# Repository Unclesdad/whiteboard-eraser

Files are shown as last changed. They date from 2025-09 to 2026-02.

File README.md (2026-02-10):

# Whiteboard Eraser

An autonomous whiteboard eraser robot built on a Raspberry Pi 5. Uses computer vision to detect markings on a whiteboard and navigates to erase them. Initially conceived as a handy and cool tool for our math teacher Mr. Perna, Mark is ready to vroom across surfaces and unmark any unwanted marks.

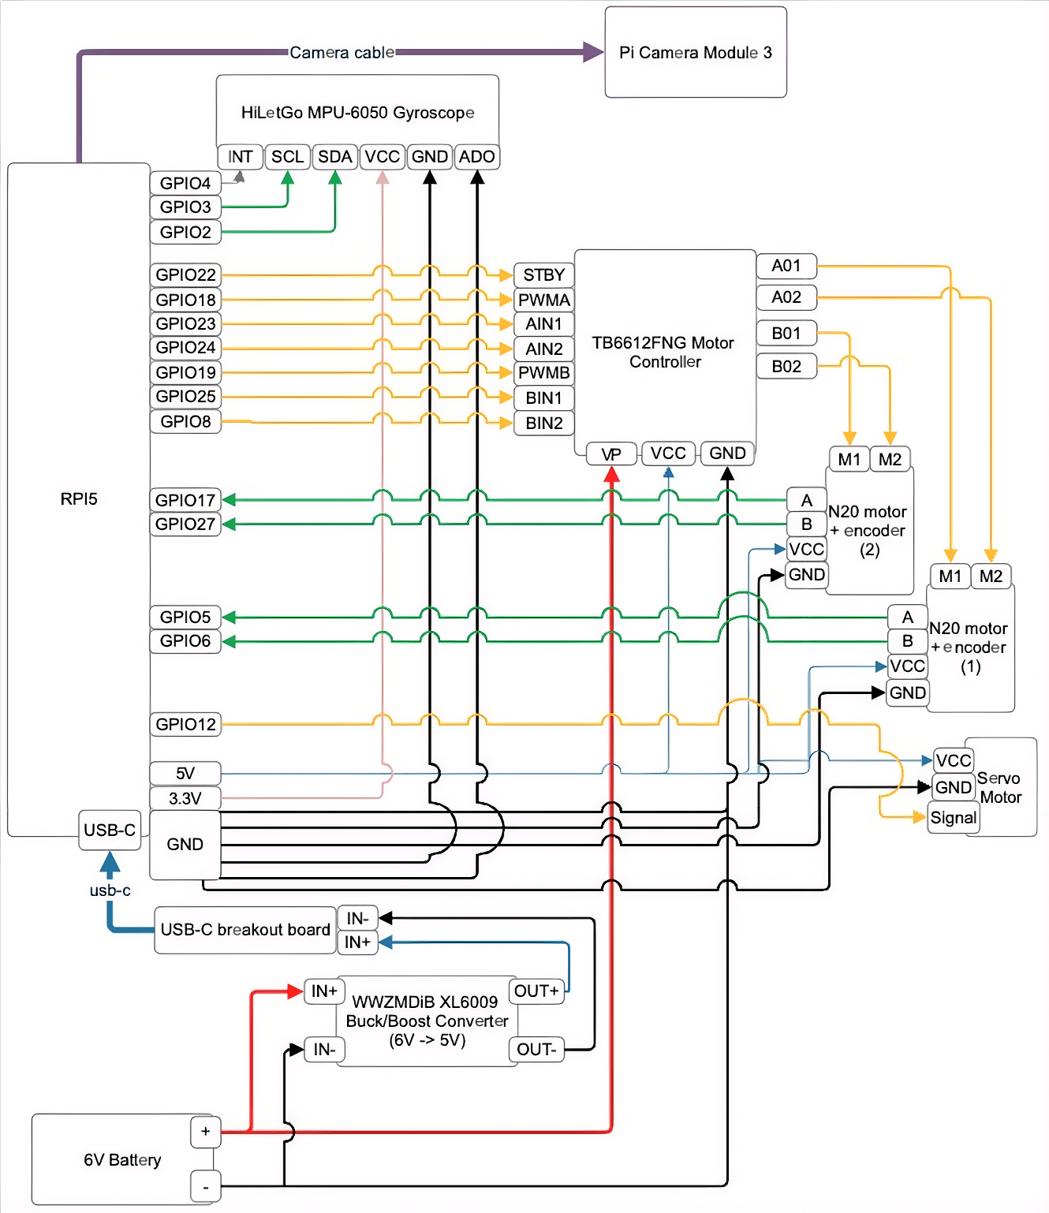
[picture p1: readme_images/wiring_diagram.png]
Wiring Diagram


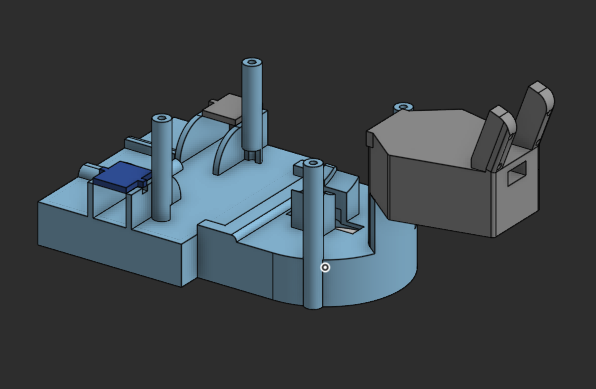
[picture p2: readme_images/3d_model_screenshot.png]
3d Model Screenshot


## Project Structure

```
whiteboard-eraser/
├── lib/                    # Hardware abstraction layer
│   ├── motor.py            # N20 motor control with encoders
│   ├── servo.py            # Steering servo control
│   └── gyro.py             # MPU-6050 gyroscope/IMU
├── src/                    # Algorithm and application code
│   ├── whiteboard_eraser_main.py   # Main control loop
│   ├── car_controller.py           # PID control for motion
│   ├── simple_marking_detector.py  # Computer vision detection
│   ├── localization.py             # Position tracking (odometry + gyro)
│   ├── mapping.py                  # Global marking map
│   ├── pathfinder.py               # A* pathfinding
│   └── ...
├── setup/                  # Installation scripts
│   ├── setup_service.sh    # Systemd service installer
│   └── install_dependencies.sh
└── ...
```

### lib/ - Hardware Abstraction

Low-level drivers that interface directly with hardware components. These modules abstract away GPIO pins, I2C communication, and PWM signals into clean Python APIs.

### src/ - Algorithms

High-level application code including computer vision, path planning, localization, and the main state machine. These modules use the hardware abstractions from `lib/` to control the robot.

## Bill of Materials

| Category | Component | Qty | Specifications | Price | Notes |
|---|---|-----|---|---|---|
| Motors | [N20 DC Gear Motor with Hall Encoder](https://a.co/d/9TnXhcp) | 4 | 6V, All-metal Gearbox, 60RPM | $22 ea | Small but powerful. Main driving force of the bot |
| Motors | [N20 DC Gear Motor w/o Encoder](https://a.co/d/ak1BJBg) | 4 | 6V, All-metal Gearbox, 60RPM | $18 ea | No encoder needed for the front wheels |
| Motor Driver | [TB6612FNG Motor Driver Board](https://www.sparkfun.com/sparkfun-motor-driver-dual-tb6612fng-1a.html) | 1 | Dual H-Bridge 1.2A per channel | $15 | |
| Steering | [Miuzei MG90S Micro Servo](https://a.co/d/aozp7PX) | 1 | 9g Metal Geared Servo Motor | $14 | 4-pack available, only need 1 for steering mechanism |
| IMU | [MPU-6050](https://a.co/d/8KAH4Vv) | 1 | 6-axis Gyroscope + Accelerometer I2C | $7 | GY-521 breakout board |
| Power | [Blomiky 6V NiMH Battery](https://a.co/d/0zdu3bS) | 1 | 2400mAh AA NiMH with SM-2P plug | $15 | RC car rechargeable battery |
| Power | [XL6009 Buck/Boost Converter](https://a.co/d/98DkTq4) | 1 | DC-DC 3.8-32V to 1.25-35V | $10 | 3-pack, adjust output to 5V for Pi5 |
| Connectivity | [Jumper Wires](https://a.co/d/bcNZuKm) | 1 set | M-F, M-M, F-F | $10 | Dupont connector wires |
| Mechanical | [Tires](https://www.injora.com/products/4pcs-1-9-108-40mm-rubber-tyre-wheel-tires-for-1-10-rc-rock-crawler) | 4 | INJORA 1.9" 108x40mm Rubber | $20 | High performance rock crawler tires |
| Magnets | [30x3mm Neodymium Magnets](https://a.co/d/8jqn8wP) | 1 set | 10 pieces | $13 | For attaching front wheels to magnetic whiteboard |
| Magnets | [2in Fishing Magnet](https://a.co/d/bWNcJSW) | 1 | Strong with hook | $10 | Main attraction force to keep car on board |

## Getting Started

See [USAGE.md](USAGE.md) for installation and usage instructions.

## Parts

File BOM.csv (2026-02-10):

Category | Component | Quantity | Specifications | Estimated Price | Purchase Link | Notes
Motors | N20 DC Gear Motor with Hall Encoder | 4 | 6V, All-metal Gearbox, L-shaped 6PIN Connector, Magnetic Hall Encoder, 60RPM | $22 each | https://a.co/d/9TnXhcp | Small but powerful. Main driving force of the bot
Motors | N20 DC Gear Motor w/o Encoder | 4 | 6V, All-metal Gearbox, Only two pins, 60RPM | $18 each | https://a.co/d/ak1BJBg | Also small but powerful. No encoder needed for the front wheels.
Motor Driver | TB6612FNG Motor Driver Board | 1 | Dual H-Bridge 1.2A per channel | $15 | https://www.sparkfun.com/sparkfun-motor-driver-dual-tb6612fng-1a.html
Steering | Miuzei MG90S Micro Servo | 1 | 9g Metal Geared Servo Motor. 4 pack | $14 | https://a.co/d/aozp7PX | 4-pack available, only need 1 for steering mechanism
IMU | MPU-6050 | 1 | 6-axis Gyroscope + Accelerometer I2C | $7 | https://a.co/d/8KAH4Vv | GY-521 breakout board
Power | Blomiky 6V NiMH Battery | 1 | 2400mAh AA NiMH with SM-2P plug + USB charge cable | $15 | https://a.co/d/0zdu3bS | RC car rechargeable battery for stunt vehicles
Power | WWZMDiB XL6009 Buck/Boost Converter | 1 | DC-DC 3.8-32V to 1.25-35V Adjustable | $10 | https://a.co/d/98DkTq4 | 3-pack, adjust output to 5V for logic boards (like pi5)
Connectivity | Jumper Wires | 1 set | Male-to-Female, Male-to-Male and Female-to-Female | $10 | https://a.co/d/bcNZuKm | Dupont connector wires
Mechanical | Tires | 4 | INJORA 1.9in 108*40mm Rubber Tires | $20 | https://www.injora.com/products/4pcs-1-9-108-40mm-rubber-tyre-wheel-tires-for-1-10-rc-rock-crawler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 | High performance rock crawler tires for 3D printed wheels
Magnets | 30x3mm Neodynium Magnets | 1 set | 10 pieces | $13 | https://a.co/d/8jqn8wP | Smaller magnets for attaching front wheels to the magnetic whiteboard
Magnets | 2in Fishing Magnet | 1 | Must have a hook and be extremely strong | $10 | https://a.co/d/bWNcJSW | Main force of attraction for the body, super strong magnet to keep car on board

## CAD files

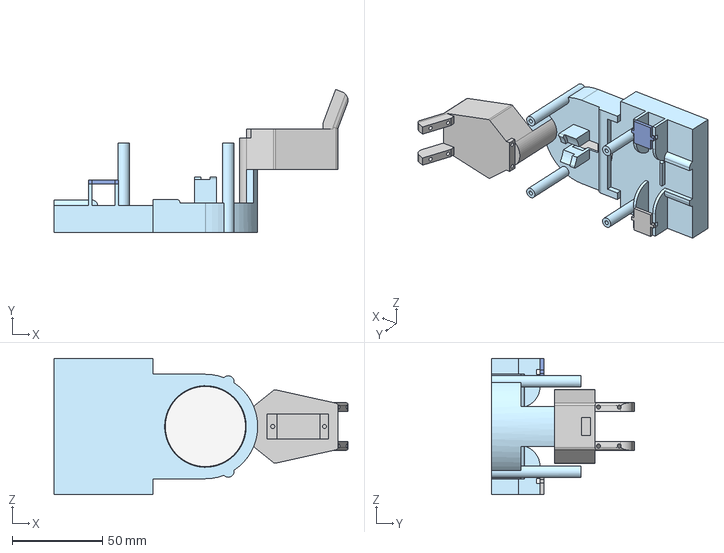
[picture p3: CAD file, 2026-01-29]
eraser car.step
163.0 x 79.3 x 75.6 mm

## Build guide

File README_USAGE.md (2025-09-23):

# Whiteboard Eraser Car - Usage Guide

## Quick Start

1. **Install dependencies:**
   ```bash
   pip install -r requirements.txt
   ```

2. **Test the system:**
   ```bash
   python test_system.py --all
   ```

3. **Run the whiteboard eraser:**
   ```bash
   python whiteboard_eraser_main.py
   ```

## Auto-Start Setup (Plug and Play)

To set up the car to start automatically when powered on:

1. **Install as a service:**
   ```bash
   sudo ./setup_service.sh
   ```

2. **Reboot the system:**
   ```bash
   sudo reboot
   ```

3. **The car will now automatically:**
   - Wait 5 seconds after boot
   - Calibrate its encoders by moving forward then backward
   - Perform a circular scan to detect markings
   - Begin systematic erasing of detected markings

4. **Monitor the service:**
   ```bash
   sudo journalctl -u whiteboard-eraser -f
   ```

## Testing Individual Components

### Test Marking Detection
```bash
python test_system.py --detection
```
Place some whiteboard images (with markings) in the directory first.

### Test Hardware Integration
```bash
python test_system.py --controller --camera
```

### Test Full System (Safe Mode)
```bash
python test_system.py --integration
```

## Command Line Options

### Main System
```bash
python whiteboard_eraser_main.py [options]

Options:
  --debug                 Enable debug mode with camera view
  --camera-width WIDTH    Camera resolution width (default: 640)
  --camera-height HEIGHT  Camera resolution height (default: 480)
  --max-speed SPEED       Maximum speed in mm/s (default: 150)
  --scan-time TIME        Maximum scan time in seconds (default: 60)
```

### Testing
```bash
python test_system.py [options]

Options:
  --all                   Run all tests
  --detection             Test marking detection only
  --localization          Test position tracking only
  --mapping               Test global mapping only
  --pathfinding           Test path planning only
  --controller            Test car control only
  --camera                Test camera integration only
  --integration           Test full system integration
```

## System Architecture

### Core Modules

1. **marking_detector.py** - Computer vision for detecting markings
2. **localization.py** - Position tracking using encoders + gyro
3. **mapping.py** - Global map of detected markings
4. **pathfinder.py** - A* pathfinding with car constraints
5. **car_controller.py** - PID control for smooth motion
6. **whiteboard_eraser_main.py** - Main control loop

### Hardware APIs (Existing)

- **motor.py** - N20 motor control with encoders
- **gyro.py** - MPU-6050 gyroscope integration
- **servo.py** - Steering servo control

## Operation States

### Startup Sequence
1. **STARTUP_DELAY** - Wait 5 seconds after power-on
2. **CALIBRATING_ENCODERS** - Move forward/backward to calibrate encoder differences
3. **INITIAL_SCAN** - Drive in circle to detect markings

### Main Operation
4. **SCANNING** - Continue detecting and mapping markings
5. **PLANNING** - Plan path to next marking cluster
6. **NAVIGATING** - Follow planned path to target
7. **ERASING** - Mark area as erased when car drives over it
8. **COMPLETED** - All markings processed

## Key Features

### Computer Vision
- Handles upside-down camera mounting (180° rotation)
- Efficient marking detection optimized for RPi5
- Real-world coordinate conversion from pixels
- Adaptive thresholding for different lighting

### Localization
- Combines wheel encoder odometry with gyroscope
- Drift-free heading using sensor fusion
- Coordinate transformations between reference frames
- Position validation and error detection

### Mapping
- Global marking map with confidence tracking
- Duplicate detection and merging
- Clustering for efficient pathfinding
- Progress tracking and persistence

### Pathfinding
- A* search with Ackermann steering constraints
- Respects minimum turning radius
- Obstacle avoidance
- Path smoothing for natural motion

### Control
- PID control for position and heading
- Smooth velocity commands
- Emergency stop capabilities
- Real-time status monitoring

## Calibration Tips

### Camera Calibration
1. Test detection on sample images first
2. Adjust `marking_threshold` if markings not detected
3. Verify coordinate conversion using known distances

### Motor Calibration
1. Check encoder tick counts per revolution
2. Measure actual wheel radius
3. Calibrate `mm_per_tick` conversion factor

### Steering Calibration
1. Verify servo center position (90°)
2. Measure actual max steering angles
3. Test turning radius calculations

## Troubleshooting

### No Markings Detected
- Check camera focus and exposure
- Verify marking contrast against whiteboard
- Test with debug mode: `--debug`

### Poor Navigation Accuracy
- Calibrate wheel encoder counts
- Check gyroscope calibration
- Verify motor speed consistency

### Path Planning Failures
- Check obstacle map boundaries
- Reduce max speed for tighter turns
- Increase planning time limit

### Hardware Issues
- Run component tests: `python test_system.py --all`
- Check GPIO connections and permissions
- Verify I2C communication for gyroscope

## Performance Optimization

### For Better Detection Speed
- Reduce camera resolution
- Lower detection frequency
- Use smaller blur kernel size

### For Better Navigation
- Increase control loop frequency
- Tune PID parameters
- Use path smoothing

### For Better Coverage
- Increase scan time
- Lower minimum confidence threshold
- Use smaller merge distance

## Safety Notes

- Always test in simulation mode first
- Use emergency stop (Ctrl+C) if needed
- Start with slow speeds for testing
- Ensure adequate clearance around whiteboard
- Monitor system status during operation

## File Output

The system saves several files during operation:

- `whiteboard_map_[timestamp].json` - Periodic map saves
- `final_whiteboard_map.json` - Complete final map
- `shutdown_map.json` - Map saved on emergency shutdown

These can be loaded later for analysis or resuming operation.

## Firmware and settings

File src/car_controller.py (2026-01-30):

#!/usr/bin/env python3
"""
Car Controller for Whiteboard Eraser Car
Implements PID control for smooth position and heading control
Integrates with existing motor.py, gyro.py, and servo.py hardware APIs
"""

import time
import threading
import sys
import os
import numpy as np
from typing import Optional, Tuple, List
from dataclasses import dataclass
from enum import Enum

# Add parent directory to path for lib imports
sys.path.insert(0, os.path.dirname(os.path.dirname(os.path.abspath(__file__))))

# Import hardware APIs
try:
    from lib.motor import N20Motor, DualMotorController
    from lib.gyro import RCCarGyro
    from lib.servo import ServoController
    import RPi.GPIO as GPIO
except ImportError:
    print("Warning: Hardware modules not available. Running in simulation mode.")

    # Mock classes for testing
    class N20Motor:
        def __init__(self, *args, **kwargs):
            self.current_speed = 0.0
            self.encoder_count = 0
        def set(self, speed): self.current_speed = speed
        def get_encoder_count(self): return self.encoder_count
        def get_revolutions(self): return self.encoder_count / 28.0
        def reset_encoder(self): self.encoder_count = 0
        def stop(self): self.current_speed = 0.0
        def cleanup(self): pass

    class DualMotorController:
        def __init__(self, *args, **kwargs): pass
        def enable(self): pass
        def disable(self): pass
        def cleanup(self): pass

    class RCCarGyro:
        def __init__(self, *args, **kwargs):
            self.angle_z = 0.0
        def calibrate(self): pass
        def start_continuous_update(self): pass
        def stop_continuous_update(self): pass
        def get_orientation(self): return (0, 0, self.angle_z)
        def reset_orientation(self): self.angle_z = 0.0

    class ServoController:
        def __init__(self, *args, **kwargs):
            self.current_angle = 90
        def set_angle(self, angle): self.current_angle = angle
        def cleanup(self): pass

    class GPIO:
        BCM = 1
        @staticmethod
        def setmode(mode): pass
        @staticmethod
        def setwarnings(flag): pass
        @staticmethod
        def cleanup(): pass

@dataclass
class PIDController:
    """PID controller for smooth control"""
    kp: float
    ki: float
    kd: float
    max_output: float = 1.0
    min_output: float = -1.0
    max_integral: float = 1.0

    def __post_init__(self):
        self.reset()

    def reset(self):
        """Reset PID controller state"""
        self.previous_error = 0.0
        self.integral = 0.0
        self.last_time = time.time()

    def update(self, error: float, dt: Optional[float] = None) -> float:
        """
        Update PID controller with new error

        Args:
            error: Current error value
            dt: Time delta (auto-calculated if None)

        Returns:
            Control output
        """
        current_time = time.time()
        if dt is None:
            dt = current_time - self.last_time

        if dt <= 0:
            return 0.0

        # Proportional term
        proportional = self.kp * error

        # Integral term with windup protection
        self.integral += error * dt
        self.integral = np.clip(self.integral, -self.max_integral, self.max_integral)
        integral = self.ki * self.integral

        # Derivative term
        derivative = self.kd * (error - self.previous_error) / dt

        # Calculate output
        output = proportional + integral + derivative
        output = np.clip(output, self.min_output, self.max_output)

        # Update state
        self.previous_error = error
        self.last_time = current_time

        return output

class CarState(Enum):
    """Car operational states"""
    STOPPED = "stopped"
    MANUAL_CONTROL = "manual"
    POSITION_CONTROL = "position"
    PATH_FOLLOWING = "path_following"
    EMERGENCY_STOP = "emergency"

@dataclass
class CarStatus:
    """Current car status"""
    state: CarState
    position_x: float
    position_y: float
    heading: float
    linear_velocity: float
    angular_velocity: float
    left_motor_speed: float
    right_motor_speed: float
    steering_angle: float
    timestamp: float

class CarController:
    """
    High-level car controller with PID control for smooth motion
    """

    def __init__(self,
                 # Motor configuration
                 left_motor_pins: dict = None,
                 right_motor_pins: dict = None,
                 standby_pin: int = 22,

                 # Servo configuration
                 servo_pin: int = 12,

                 # Gyro configuration
                 gyro_sda_pin: int = 2,
                 gyro_scl_pin: int = 3,

                 # Car physical parameters
                 wheelbase_mm: float = 110.0,
                 track_width_mm: float = 110.0,
                 wheel_radius_mm: float = 30.0,
                 max_speed_mm_s: float = 200.0,

                 # Control parameters
                 update_rate_hz: float = 50.0):
        """
        Initialize car controller

        Args:
            left_motor_pins: Dict with keys: pwm_pin, dir1_pin, dir2_pin, enc_a_pin, enc_b_pin
            right_motor_pins: Dict with keys: pwm_pin, dir1_pin, dir2_pin, enc_a_pin, enc_b_pin
            Other args: Hardware pins and car parameters
        """

        # Default motor pin configurations
        if left_motor_pins is None:
            left_motor_pins = {
                'pwm_pin': 18, 'dir1_pin': 23, 'dir2_pin': 24,
                'enc_a_pin': 17, 'enc_b_pin': 27
            }

        if right_motor_pins is None:
            right_motor_pins = {
                'pwm_pin': 19, 'dir1_pin': 25, 'dir2_pin': 8,
                'enc_a_pin': 5, 'enc_b_pin': 6
            }

        # Store parameters
        self.wheelbase_mm = wheelbase_mm
        self.track_width_mm = track_width_mm
        self.wheel_radius_mm = wheel_radius_mm
        self.max_speed_mm_s = max_speed_mm_s
        self.update_rate_hz = update_rate_hz
        self.update_interval = 1.0 / update_rate_hz

        # Initialize GPIO (critical - robot cannot function without GPIO access)
        try:
            GPIO.setmode(GPIO.BCM)
            GPIO.setwarnings(False)
            self.hardware_available = True
            print("GPIO initialized successfully")
        except Exception as e:
            print(f"CRITICAL: GPIO initialization failed: {e}")
            print("Solutions:")
            print("  - Run with: sudo python3 whiteboard_eraser_main.py")
            print("  - Check if another process is using GPIO")
            print("  - Verify you're running on a Raspberry Pi")
            print("\nCannot control hardware without GPIO access - stopping program")
            raise RuntimeError("GPIO initialization failed - robot cannot access hardware")

        # Initialize hardware (will fall back to mock if GPIO failed)
        self._init_motors(left_motor_pins, right_motor_pins, standby_pin)
        self._init_servo(servo_pin)
        self._init_gyro(gyro_sda_pin, gyro_scl_pin)

        # Initialize PID controllers
        self._init_pid_controllers()

        # State management
        self.state = CarState.STOPPED
        self.state_lock = threading.Lock()

        # Position tracking
        self.position_x = 0.0
        self.position_y = 0.0
        self.heading = 0.0
        self.target_x = 0.0
        self.target_y = 0.0
        self.target_heading = 0.0

        # Velocity tracking
        self.linear_velocity = 0.0
        self.angular_velocity = 0.0

        # Odometry tracking (for delta calculations)
        self.prev_left_revs = 0.0
        self.prev_right_revs = 0.0

        # Control thread
        self.control_thread = None
        self.running = False

        # Safety limits
        self.max_steering_angle = 45.0  # degrees (±45° from center)
        self.emergency_stop_flag = False

        print(f"CarController initialized:")
        print(f"  Wheelbase: {wheelbase_mm}mm, Track: {track_width_mm}mm")
        print(f"  Max speed: {max_speed_mm_s}mm/s")
        print(f"  Update rate: {update_rate_hz}Hz")
        if self.hardware_available:
            print(f"  Hardware: Real GPIO detected")
        else:
            print(f"  Hardware: Using mock/simulation mode")

    def _init_motors(self, left_pins: dict, right_pins: dict, standby_pin: int):
        """Initialize motor controllers"""
        try:
            # Create motor controller
            self.motor_controller = DualMotorController(standby_pin)

            # Create individual motors
            self.left_motor = N20Motor(name="Left Motor", **left_pins)
            self.right_motor = N20Motor(name="Right Motor", **right_pins)

            # Assign to controller
            self.motor_controller.motor_a = self.left_motor
            self.motor_controller.motor_b = self.right_motor

            # Reset encoders
            self.left_motor.reset_encoder()
            self.right_motor.reset_encoder()

            print("Motors initialized successfully")

        except Exception as e:
            print(f"CRITICAL: Motor initialization failed: {e}")

            # Check if this is the specific SOC error that needs detailed diagnosis
            if "soc peripheral base address" in str(e).lower():
                print("\nRunning detailed hardware diagnostics...")

                # Try to create a temporary motor instance to get the detailed diagnostics
                try:
                    temp_motor = N20Motor(
                        pwm_pin=left_pins['pwm_pin'],
                        dir1_pin=left_pins['dir1_pin'],
                        dir2_pin=left_pins['dir2_pin'],
                        enc_a_pin=left_pins['enc_a_pin'],
                        enc_b_pin=left_pins['enc_b_pin'],
                        name="Diagnostic Motor"
                    )
                except Exception as motor_error:
                    # This should trigger the detailed diagnostics in motor.py
                    print(f"(Diagnostic attempt also failed, which provided the above details)")

            else:
                # For other errors, show the generic troubleshooting
                print("This could be due to:")
                print("  - Need to run with 'sudo python3 whiteboard_eraser_main.py'")
                print("  - Motor drivers not connected to GPIO pins")
                print("  - Incorrect wiring (check left_motor_pins and right_motor_pins)")
                print("  - Hardware failure in motor drivers or Pi GPIO")
                print("  - Wrong GPIO pin numbers in configuration")

            print("\nCannot operate robot without motors - stopping program")
            raise RuntimeError("Motor hardware initialization failed - robot cannot function")

    def _init_servo(self, servo_pin: int):
        """initialize steering servo"""
        try:
            self.servo = ServoController(servo_pin)
            self.servo.set_angle(90)  # Center position
            print("Servo initialized successfully")
        except Exception as e:
            print(f"CRITICAL: Servo initialization failed: {e}")
            print("This could be due to:")
            print(f"  - Servo not connected to GPIO pin {servo_pin}")
            print("  - Incorrect servo wiring (check power, ground, signal)")
            print("  - GPIO pin conflict or hardware failure")
            print("\nCannot steer robot without servo - stopping program")
            raise RuntimeError("Servo hardware initialization failed - robot cannot steer")

    def _init_gyro(self, sda_pin: int, scl_pin: int):
        """initialize gyroscope"""
        try:
            self.gyro = RCCarGyro(sda_pin=sda_pin, scl_pin=scl_pin)
            self.gyro.calibrate(samples=500, show_progress=False)
            self.gyro.start_continuous_update(update_rate=50)
            print("Gyroscope initialized and calibrated")
        except Exception as e:
            print(f"WARNING: Gyroscope initialization failed: {e}")
            print("This could be due to:")
            print(f"  - IMU not connected to I2C pins (SDA={sda_pin}, SCL={scl_pin})")
            print("  - I2C not enabled (run 'sudo raspi-config' -> Interface Options -> I2C)")
            print("  - Incorrect IMU wiring or hardware failure")
            print("  - Wrong I2C address or conflicting I2C devices")
            print("\nRobot will operate with reduced accuracy (dead reckoning only)")

            class MockGyro:
                def __init__(self):
                    self.angle_z = 0.0
                    self.is_calibrated = True
                def calibrate(self, samples=500, show_progress=False): pass
                def start_continuous_update(self, update_rate=50): pass
                def stop_continuous_update(self): pass
                def get_orientation(self): return (0, 0, self.angle_z)
                def reset_orientation(self): self.angle_z = 0.0

            self.gyro = MockGyro()

    def _init_pid_controllers(self):
        """Initialize PID controllers"""
        # Position PID (output: linear velocity)
        self.position_pid = PIDController(
            kp=0.8,  # Proportional gain
            ki=0.1,  # Integral gain
            kd=0.2,  # Derivative gain
            max_output=1.0,
            min_output=-1.0,
            max_integral=0.5
        )

        # Heading PID (output: angular velocity)
        self.heading_pid = PIDController(
            kp=1.2,
            ki=0.05,
            kd=0.3,
            max_output=1.0,
            min_output=-1.0,
            max_integral=0.3
        )

        # Speed PID controllers for each motor
        self.left_speed_pid = PIDController(
            kp=0.5,
            ki=0.1,
            kd=0.05,
            max_output=1.0,
            min_output=-1.0
        )

        self.right_speed_pid = PIDController(
            kp=0.5,
            ki=0.1,
            kd=0.05,
            max_output=1.0,
            min_output=-1.0
        )

    def start_control_loop(self):
        """Start the main control loop"""
        if self.running:
            return

        self.running = True
        self.control_thread = threading.Thread(target=self._control_loop, daemon=True)
        self.control_thread.start()
        print("Control loop started")

    def stop_control_loop(self):
        """Stop the main control loop"""
        if not self.running:
            return

        self.running = False
        if self.control_thread:
            self.control_thread.join(timeout=1.0)

        self.stop_all_motors()
        print("Control loop stopped")

    def _control_loop(self):
        """Main control loop running at specified frequency"""
        last_time = time.time()

        while self.running:
            loop_start = time.time()
            dt = loop_start - last_time

            try:
                # Update odometry
                self._update_odometry(dt)

                # Execute control based on current state
                with self.state_lock:
                    if self.state == CarState.POSITION_CONTROL:
                        self._position_control_update(dt)
                    elif self.state == CarState.MANUAL_CONTROL:
                        pass  # Manual commands handled separately
                    elif self.state == CarState.EMERGENCY_STOP:
                        self.stop_all_motors()

            except Exception as e:
                print(f"Error in control loop: {e}")
                self.emergency_stop()

            # Maintain loop timing
            last_time = loop_start
            elapsed = time.time() - loop_start
            sleep_time = max(0, self.update_interval - elapsed)
            if sleep_time > 0:
                time.sleep(sleep_time)

    def _update_odometry(self, dt: float):
        """Update position and velocity estimates"""
        if dt <= 0:
            return

        # Get encoder readings (cumulative revolutions)
        left_revs = self.left_motor.get_revolutions()
        right_revs = self.right_motor.get_revolutions()

        # Calculate DELTA revolutions since last update
        delta_left_revs = left_revs - self.prev_left_revs
        delta_right_revs = right_revs - self.prev_right_revs

        # Store for next iteration
        self.prev_left_revs = left_revs
        self.prev_right_revs = right_revs

        # Calculate incremental distances traveled this update
        left_distance = delta_left_revs * 2 * np.pi * self.wheel_radius_mm
        right_distance = delta_right_revs * 2 * np.pi * self.wheel_radius_mm

        # For now, use gyro for heading
        try:
            _, _, gyro_heading = self.gyro.get_orientation()
            self.heading = np.radians(gyro_heading)
        except:
            pass  # Keep previous heading if gyro fails

        # Velocity estimation from incremental distance
        forward_distance = (left_distance + right_distance) / 2.0
        self.linear_velocity = forward_distance / dt if dt > 0 else 0

        # Update position using incremental distance
        self.position_x += forward_distance * np.cos(self.heading)
        self.position_y += forward_distance * np.sin(self.heading)

    def _position_control_update(self, dt: float):
        """Update position control"""
        # Calculate position error
        dx = self.target_x - self.position_x
        dy = self.target_y - self.position_y
        distance_error = np.sqrt(dx*dx + dy*dy)

        # Calculate heading error
        target_heading = np.arctan2(dy, dx)
        heading_error = self._normalize_angle(target_heading - self.heading)

        # PID control
        linear_cmd = self.position_pid.update(distance_error, dt)
        angular_cmd = self.heading_pid.update(heading_error, dt)

        # Convert to motor commands
        self._set_velocity_commands(linear_cmd, angular_cmd)

        # Check if we've reached the target
        if distance_error < 20.0:  # 20mm tolerance
            self.stop_all_motors()
            with self.state_lock:
                self.state = CarState.STOPPED

    def set_target_position(self, x: float, y: float, heading: float = None):
        """Set target position for position control"""
        self.target_x = x
        self.target_y = y
        if heading is not None:
            self.target_heading = heading

        # Reset PID controllers
        self.position_pid.reset()
        self.heading_pid.reset()

        with self.state_lock:
            self.state = CarState.POSITION_CONTROL

        print(f"Target set: ({x:.1f}, {y:.1f})")

    def set_manual_control(self, linear_speed: float, angular_speed: float):
        """Set manual velocity commands"""
        with self.state_lock:
            self.state = CarState.MANUAL_CONTROL

        self._set_velocity_commands(linear_speed, angular_speed)

    def _set_velocity_commands(self, linear: float, angular: float):
        """Convert velocity commands to motor speeds"""
        # Clamp inputs
        linear = np.clip(linear, -1.0, 1.0)
        angular = np.clip(angular, -1.0, 1.0)

        # Differential drive kinematics
        # linear: forward speed (-1 to 1)
        # angular: turning speed (-1 to 1, positive = turn right)

        left_speed = linear - angular * 0.5
        right_speed = linear + angular * 0.5

        # Clamp to motor limits
        left_speed = np.clip(left_speed, -1.0, 1.0)
        right_speed = np.clip(right_speed, -1.0, 1.0)

        # Set motor speeds
        self.left_motor.set(left_speed)
        self.right_motor.set(right_speed)

    def set_steering_angle(self, angle_degrees: float):
        """Set front wheel steering angle"""
        # Clamp to servo limits
        angle_degrees = np.clip(angle_degrees, -self.max_steering_angle, self.max_steering_angle)

        # Convert to servo position (90° = center)
        servo_angle = 90 + angle_degrees
        servo_angle = np.clip(servo_angle, 45, 135)  # ±45° from center

        self.servo.set_angle(int(servo_angle))

    def stop_all_motors(self):
        """Stop all motors immediately"""
        try:
            if hasattr(self, 'left_motor') and self.left_motor is not None:
                self.left_motor.stop()
        except Exception:
            pass

        try:
            if hasattr(self, 'right_motor') and self.right_motor is not None:
                self.right_motor.stop()
        except Exception:
            pass

    def emergency_stop(self):
        """Emergency stop - stop all motion and set emergency state"""
        self.emergency_stop_flag = True

        try:
            self.stop_all_motors()
        except Exception:
            pass

        try:
            if hasattr(self, 'servo') and self.servo is not None:
                self.servo.set_angle(90)  # Center steering
        except Exception:
            pass

        with self.state_lock:
            self.state = CarState.EMERGENCY_STOP

        print("EMERGENCY STOP ACTIVATED")

    def reset_emergency_stop(self):
        """Reset emergency stop state"""
        self.emergency_stop_flag = False
        with self.state_lock:
            self.state = CarState.STOPPED
        print("Emergency stop reset")

    def reset_position(self, x: float = 0.0, y: float = 0.0, heading: float = 0.0):
        """Reset current position estimate"""
        self.position_x = x
        self.position_y = y
        self.heading = heading

        # Reset motor encoders
        self.left_motor.reset_encoder()
        self.right_motor.reset_encoder()

        # Reset gyro orientation
        self.gyro.reset_orientation()

        print(f"Position reset to ({x:.1f}, {y:.1f}, {np.degrees(heading):.1f}°)")

    def get_status(self) -> CarStatus:
        """Get current car status"""
        with self.state_lock:
            state = self.state
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

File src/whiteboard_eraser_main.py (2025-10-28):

#!/usr/bin/env python3
"""
Whiteboard Eraser Car - Main Control Script
Integrates all systems for autonomous marking detection and erasure
"""

import cv2
import numpy as np
import time
import threading
import signal
import sys
from typing import Optional, Tuple
from dataclasses import dataclass
from enum import Enum

# Import our custom modules
from simple_marking_detector import SimpleMarkingDetector
from localization import LocalizationSystem
from mapping import GlobalMap
from pathfinder import AckermannPathfinder, ObstacleMap, Path, CarConfig
from car_controller import CarController, CarState

# Import camera
try:
    from picamera2 import Picamera2
    CAMERA_AVAILABLE = True
except ImportError:
    print("Warning: picamera2 not available. Running without camera.")
    CAMERA_AVAILABLE = False

class EraserState(Enum):
    """Main state machine states"""
    INITIALIZING = "initializing"
    STARTUP_DELAY = "startup_delay"
    WHITEBOARD_MAPPING = "whiteboard_mapping"
    INITIAL_SCAN = "initial_scan"
    SCANNING = "scanning"
    PLANNING = "planning"
    NAVIGATING = "navigating"
    ERASING = "erasing"
    COMPLETED = "completed"
    ERROR = "error"

@dataclass
class EraserConfig:
    """Configuration for the eraser system"""
    # Camera settings
    camera_width: int = 640
    camera_height: int = 480
    camera_fps: int = 10

    # Detection settings
    detection_interval: float = 0.2  # seconds between detections
    min_marking_confidence: float = 0.4

    # Navigation settings
    goal_tolerance_mm: float = 25.0
    max_speed_mm_s: float = 150.0
    erase_radius_mm: float = 25.0

    # Safety settings
    max_planning_time: float = 10.0
    max_navigation_time: float = 30.0

    # Performance settings
    max_scan_time: float = 60.0  # seconds to scan before starting erasure
    save_map_interval: float = 30.0  # seconds between map saves

    # Startup calibration settings
    startup_delay: float = 12.0  # seconds to wait for gyro calibration + system init
    gyro_calibration_samples: int = 1000  # gyro calibration samples
    whiteboard_mapping_time: float = 20.0  # seconds to map whiteboard orientation
    circle_scan_time: float = 15.0  # seconds for additional marking scan
    circle_radius_mm: float = 300.0  # radius of scanning circle

class WhiteboardEraserMain:
    """
    Main control system for autonomous whiteboard eraser car
    """

    def __init__(self, config: EraserConfig = None, debug: bool = False):
        """
        Initialize the whiteboard eraser system

        Args:
            config: System configuration
            debug: Enable debug mode with visualization
        """
        self.config = config or EraserConfig()
        self.debug = debug

        # System state
        self.state = EraserState.INITIALIZING
        self.state_lock = threading.Lock()
        self.running = False
        self.shutdown_requested = False

        # Initialize subsystems
        self.marking_detector: Optional[SimpleMarkingDetector] = None
        self.localization: Optional[LocalizationSystem] = None
        self.global_map: Optional[GlobalMap] = None
        self.pathfinder: Optional[AckermannPathfinder] = None
        self.car_controller: Optional[CarController] = None
        self.camera: Optional[Picamera2] = None

        # Threading
        self.main_thread: Optional[threading.Thread] = None
        self.camera_thread: Optional[threading.Thread] = None

        # Performance tracking
        self.start_time = time.time()
        self.last_detection_time = 0.0
        self.last_map_save_time = 0.0

        # Current navigation
        self.current_path: Optional[Path] = None
        self.current_target: Optional[Tuple[float, float]] = None
        self.navigation_start_time = 0.0
        self.expected_nav_time = 0.0  # Fallback for time-based navigation when encoders don't work

        # Statistics
        self.total_markings_detected = 0
        self.total_markings_erased = 0
        self.total_distance_traveled = 0.0

        # Encoder calibration data (removed - not needed)
        self.left_encoder_scale = 1.0
        self.right_encoder_scale = 1.0

        # Whiteboard orientation mapping
        self.whiteboard_right_angle = 0.0  # Gyro angle pointing to right edge (start position)
        self.whiteboard_up_angle = 0.0     # Gyro angle pointing up (against gravity)
        self.whiteboard_left_angle = 0.0   # Gyro angle pointing to left edge
        self.whiteboard_down_angle = 0.0   # Gyro angle pointing down (with gravity)
        self.whiteboard_mapped = False
        self.mapping_start_angle = 0.0
        self.mapping_angles = []  # Store angles during mapping

        # State timing
        self.state_start_time = 0.0
        self.gyro_calibration_complete = False

        print("WhiteboardEraserMain initialized")
        self._setup_signal_handlers()

    def _setup_signal_handlers(self):
        """Setup signal handlers for graceful shutdown"""
        def signal_handler(signum, _):
            print(f"\nReceived signal {signum}. Shutting down...")
            self.shutdown()
            sys.exit(0)

        signal.signal(signal.SIGINT, signal_handler)
        signal.signal(signal.SIGTERM, signal_handler)

    def initialize_systems(self) -> bool:
        """
        Initialize all subsystems

        Returns:
            True if initialization successful
        """
        try:
            print("Initializing subsystems...")

            # Initialize marking detector
            # Use SimpleMarkingDetector with correct camera parameters
            # Camera is at 7.5cm (75mm) height, 20.5° down angle
            self.marking_detector = SimpleMarkingDetector(
                camera_height_mm=75.0,  # 7.5cm above whiteboard
                camera_angle_deg=20.5,  # Camera tilt angle
                image_width=self.config.camera_width,
                image_height=self.config.camera_height,
                debug=self.debug
            )
            print("Marking detector initialized (SimpleMarkingDetector)")
            print(f"  Camera: {self.config.camera_width}x{self.config.camera_height}, 75.0mm height, 20.5° angle")

            # Initialize localization
            self.localization = LocalizationSystem()
            # Try to load previous whiteboard orientation
            self._load_whiteboard_orientation()
            print("Localization system initialized")

            # Initialize global map
            self.global_map = GlobalMap(
                min_confidence=self.config.min_marking_confidence,
                erase_confirmation_distance=self.config.erase_radius_mm
            )
            print("Global map initialized")
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

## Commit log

2025-08-07 forget it we'll just filter out bad ones by seeing where they end us up
2025-08-19 full odometry and everything. supposedlygit add .
2025-08-20 added in motor controller with encoder. finally god finally it works
2025-08-22 better frame rate ig uess
2025-08-22 change camera configuration in streaming
2025-08-22 new camera stream for testing
2025-08-25 new camera stream with the new tracker5 processing
2025-08-25 implemented flipping options for an upside down mount (which im doing lol
2025-08-25 needed to adjust settings of the camera
2025-08-25 yet another change. added in the camera_stream.py i was using earlier and copied the stats from that
2025-08-25 manual camera setup
2025-08-25 removed forcing RGB888 format and doing RGB→BGR conversions
2025-08-25 was detecting frame edges
2025-09-11 some tests for assembled car
2025-09-23 stopped detecting the ground (instead of the board)
2025-09-23 improved (?) whiteboard marking positioning with a simple test file. also made the camera stream better
2025-09-23 removed camera brightness auto-adjust
2025-09-23 woah too low brightness
    [simple_camera_stream.py]
2025-09-23 holes in the white mask of the detected whiteboard surface are the new detected markings
2025-09-24 parameterized camera width and height
2025-09-24 should have better error handling now
    [car_controller.py]
2025-09-24 went back to old motor file that worked
2025-09-24 better encoder readings? i think we'll have to test it amiright
2025-09-28 pi was taking too much power so had to make some optimization changes
    [simple_camera_stream.py]
2025-09-29 now doesn't fill markings in cv detection
    [simple_marking_detector.py]
2025-09-29 changed camera state
2025-09-30 forward_then_backward sets servo to 0
2025-09-30 encoder conversions
2025-09-30 gyro updates
2025-09-30 cumulative gyro now. was wrapped from -180 to 180
2025-10-08 lightweight detector without streaming to account for powerhungry streaming algorithm
2025-10-08 put back tuned constants for cameras
2025-10-22 fixed issues with main
    [car_controller.py, whiteboard_eraser_main.py]
2025-10-27 made forward_then_backward.py 100 percent powergit add forward_then_backward.pygit add forward_then_backward.py
2026-01-29 add picture to readme
    [BOM.csv, eraser car.step]
2026-01-29 add 3d model screenshot, more stuff to BOM, and update readme
    [BOM.csv]
2026-01-30 fix bom
    [BOM.csv]
2026-01-30 rearranging and making sure lib doesn't get gitignored
    [car_controller.py, forward_then_backward.py]
2026-01-31 readme bom
